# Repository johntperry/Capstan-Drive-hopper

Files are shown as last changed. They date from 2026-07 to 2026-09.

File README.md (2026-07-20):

# Capstan-Drive
A Capstan Drive is a cheap rope-driven speed reducer that has low backlash, low inertia, low noise, and high torque transparency. 
When it comes to building robots a Capstan Drive can be quite beneficial. This test stand has the following features:

-3D printed in PLA

-Weighs 852g

-120° rotation

-8.55:1 reduction (quasi-direct drive)

-Helical pattern on both drums for guided unraveling

-Lead screw to tension the rope

-ODrive S1 FOC Controller

-Eagle Power 90KV BLDC Motor

Test Stand5

# Attribution

Credit to Aaed Musa.

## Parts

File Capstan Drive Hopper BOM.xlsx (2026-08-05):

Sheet: Hopper BOM
 | Capstan Drive Hopper BOM
 | Part Name | Source | Price of Component / £ | Qty. Required | Qty. Desired | Qty. Desired Cost / £
Generic Parts | T-Motor P60 Pins 170KV | 3DXR (https://www.3dxr.co.uk/products/t-motor-t-motor-p60-pins?_pos=2&_sid=a328b846b&_ss=r) | 107.9 | 2 | 2 | 215.8
 | Moteus x1 Motor Controller | MJBots (https://mjbots.com/products/moteus-x1) | 130.82 | 2 | 2 | 261.64 | Get as expedited shipping such that it will get here early next week
 | Big-ticket items subtotal / £ |  |  |  |  | 477.44
 | 15x24x5mm Thin Section Bearing | Accu (https://www.accu.co.uk/thin-section-ball-bearings/986961-S61802) | 1.46-2.88 | 3 | 3 | 7.02
 | 40x50x6mm Thin Section Bearing | Amazon (https://www.amazon.co.uk/sourcing-map-6708-2RS-Groove-Bearings/dp/B085NCZBMC) | 6.49 | 4 | 4 | 25.96 | If this is not available on Amazon Business please let me know ASAP
 | Mastrant M2 Premium (100M drum) | Moonraker (https://moonrakeronline.com/mastrant-m-guy-rope) | 39.95 | 1 | 1 | 39.95
 | M2 x 14mm Phillips Pan-Head Screw | Accu (https://www.accu.co.uk/phillips-pan-head-screws/65368-SIP-M2-14-A2) | 0.04-0.84 | 8 | 12 | 2.04
 | M2 Heat-Fix Threaded Insert | Accu (https://www.accu.co.uk/brass-threaded-inserts/985938-HTFBI-M2-BR) | 0.05-0.80 | 8 | 12 | 1.68
 | M2 8mm Stand-off | Accu (https://www.accu.co.uk/threaded-standoffs/464634-HHTPS-M2-4-8-BR-NI) | 0.51-1.56 | 8 | 12 | 9.24
 | M3 Heat-Fix Threaded Insert | Accu (https://www.accu.co.uk/brass-threaded-inserts/849039-HTBTEI-M3-BR) | 0.08-0.88 | 8 | 12 | 2.4
 | M3 x 8mm Countersunk Screw | Accu (https://www.accu.co.uk/countersunk-socket-head-screws/5423-SSK-M3-8-A2) | 0.02-0.78 | 8 | 12 | 1.44
 | M3 x 40mm Cap Head Screw | Accu (https://www.accu.co.uk/metric-cap-head-screws/2807-SSC-M3-40-A2) | 0.06-0.86 | 2 | 2 | 1
 | M3 x 16mm Cap Head Screw | Accu (https://www.accu.co.uk/metric-cap-head-screws/3822-SSCF-M3-16-A2) | 0.02-0.79 | 8 | 12 | 1.56
 | M4 x 16mm Cap Head Screw | Accu (https://www.accu.co.uk/metric-cap-head-screws/3841-SSCF-M4-16-A2) | 0.04-0.83 | 8 | 12 | 1.92
 | M4 Locking Nut | Accu (https://www.accu.co.uk/hexagon-nylon-locking-nuts/7946-HNN-M4-A2) | 0.02-0.78 | 11 | 12 | 1.44
 | M4 x 28mm Pan Head Screw | Accu (https://www.accu.co.uk/torx-pan-head-screws/475422-SHP-M4-28-V2-A2) | 0.09-0.98 | 8 | 8 | 2.64
 | M4 x 40mm Cap Head Screw | Accu (https://www.accu.co.uk/metric-cap-head-screws/2833-SSC-M4-40-A2) | 0.08-0.90 | 3 | 4 | 1.48
 | M4 x 55mm Cap Head Screw | Accu (https://www.accu.co.uk/metric-cap-head-screws/2836-SSC-M4-55-A2) | 0.11-0.98 | 1 | 2 | 1.22
 | M4 x 100mm Cap Head Screw | Accu (https://www.accu.co.uk/metric-cap-head-screws/10645-SSC-M4-100-A2) | 1.58-3.63 | 1 | 2 | 6.04
 | M6 Locking Nut | Accu (https://www.accu.co.uk/hexagon-nylon-locking-nuts/7948-HNN-M6-A2) | 0.03-0.8 | 4 | 4 | 1.12
 | M6 x 150mm Cap Head Screw | Accu (https://www.accu.co.uk/metric-cap-head-screws/2890-SSC-M6-150-A2) | 0.63-2.06 | 4 | 4 | 5.52
 | M6 x 30mm Cap Head Screw | Accu (https://www.accu.co.uk/metric-cap-head-screws/2872-SSC-M6-30-A2) | 0.09-0.94 | 4 | 4 | 1.6
 | Other parts subtotal / £ |  |  |  |  | 115.27
 | Total Part Cost / £ |  |  |  |  | 592.71
 |  |  |  |  |  |  |  | 10.25

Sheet: 3D Printing
IGNORE FOR NOW
3D-Printed Parts | Part Name | Material | Weight of Component / g | Qty. Required | Qty. Desired | Qty. Cost of Material | Source from normal filament location
 | Hopper_Base PLA | PLA | 333 | 1 | 1 | 3.41325 | Est. PLA Cost Per kg / £
 | Controller_Cover PLA | PLA | 19.14 | 2 | 2 | 0.39237
 | Cover_Under PLA | PLA | 98.47 | 1 | 1 | 1.0093175
 | Cover PLA | PLA | 28.25 | 1 | 1 | 0.2895625
 | Small_Pulley Resin (2 Parts) | Resin | n/a | 1 | 2
 | Big_Drum_Hip PLA | PLA | 172.4 | 2 | 2 | 3.5342
 | Calf_Body PLA | PLA | 58.36 | 2 | 2 | 1.19638
 | Total 3DP Filament Cost / £ |  |  |  |  | 9.83508
 | Total Hopper Cost / £ |  |  |  |  | 602.54508

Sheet: Alternate Motors
 | Money Criteria |  |  |  |  |  |  | Physical Properties
 | Part Name | Source | Price of Component / £ | Shipping, VAT inc.? | Qty. Required | Qty. Desired | Qty. Desired Cost / £ | Mass / g | Operating Voltage / V | Peak cont. power / W | KV Value / RPM/V | Peak Current / A | Stall torque (est) / Nm | ST per kg / Nm/kg
Current | Eaglepower 8308 KV90 | AliExpress (https://www.aliexpress.com/item/1005003421356221.html) | 65.72 |  | 2 | 2 | 131.44 | 336 |  | 900 | 90 | 22 | 2.334272499 | 6.947239579 | Aaed Musa's Design (https://www.aaedmusa.com/projects/capstandrive)
 | MAD Components M6C06 | MAD (https://mad-motor.com/products/m6c06-eee-v3-brushless-drone-motor?VariantsId=11290) | 74.43 |  | 2 | 2 | 148.86 | 157 |  | 1075 | 160 | 22.43 | 1.338692015 | 8.526700733
 | MAD Components M8S C08 | MAD (https://mad-motor.com/products/m8s-c08-ipe-brushless-drone-motor) | 202.62 |  | 2 | 2 | 405.24 | 280 |  | 1490 | 100 | 31.8 | 3.036676314 | 10.84527255
 | Hobbywing M6215-HIGHTPROT | Hobbywing (https://hobbywinguav.com/product/m6215-hightprot/) | 59.03 |  | 2 | 2 | 118.06 | 270 |  | 950? | 160 | 38.6 | 2.303767801 | 8.532473338 | French Warehouse, Conflicting Pmax information
 | Hobbywing M8110 Light | Hobbywing (https://hobbywinguav.com/product/m8110-light/) | 88.97 |  | 2 | 2 | 177.94 | 300.5 |  | 2000? | 95 | 43.3 | 4.352468865 | 14.4840894 | French Warehouse, Conflicting Pmax information
 | Hobbywing M8108 Light | Hobbywing (https://hobbywinguav.com/product/m8108-light/) | 91.53 |  | 2 | 2 | 183.06 | 238.3 |  | 950? | 100 | 33.8 | 3.227662246 | 13.54453313 | French Warehouse, Conflicting Pmax information
 | T-Motor Antigravity MN5006 | 3DXR (https://www.3dxr.co.uk/products/t-motor-antigravity-5006) | 84.99 |  | 2 | 2 | 169.98 | 108 |  | 500 | 300 | 20 | 0.6366197724 | 5.894627522
 | T-Motor Antigravity 5008 170KV | 3DXR (https://www.3dxr.co.uk/products/t-motor-antigravity-5008) | 89.99 |  | 2 | 2 | 179.98 | 128 |  | 720 | 170 | 15 | 0.8425849928 | 6.582695257
 | T-Motor Antigravity 5008 340KV | 3DXR (https://www.3dxr.co.uk/products/t-motor-antigravity-5008) | 89.99 |  | 2 | 2 | 179.98 | 135 |  | 760 | 340 | 35 | 0.983015825 | 7.281598704
 | T-Motor MN4112 320KV | 3DXR (https://www.3dxr.co.uk/products/t-motor-mn4112) | 92.99 |  | 2 | 2 | 185.98 | 172 |  | 910 | 320 | 40 | 1.193662073 | 6.939895774
 | T-Motor MN5208 340KV | 3DXR (https://www.3dxr.co.uk/products/t-motor-mn5208-kv340) | 99.9 |  | 2 | 2 | 199.8 | 196 | 24 | 850 | 340 | 35 | 0.983015825 | 5.015386862
 | T-Motor MN501-S 240KV | 3DXR (https://www.3dxr.co.uk/products/t-motor-mn501-s) | 99.9 |  | 2 | 2 | 199.8 | 170 | 25-50 | 1200 | 240 | 25 | 0.9947183943 | 5.851284672
 | T-Motor MN501-S 300KV | 3DXR (https://www.3dxr.co.uk/products/t-motor-mn501-s) | 99.9 |  | 2 | 2 | 199.8 | 170 | 25-30 | 1000 | 300 | 40 | 1.273239545 | 7.489644381
 | T-Motor P60 Pins 170KV | 3DXR (https://www.3dxr.co.uk/products/t-motor-t-motor-p60-pins?_pos=2&_sid=a328b846b&_ss=r) | 107.9 |  | 2 | 2 | 215.8 | 375 | 48 | 1800 | 170 | 38 | 2.134548649 | 5.692129729
 | T-Motor P60 Pins 340KV | 3DXR (https://www.3dxr.co.uk/products/t-motor-t-motor-p60-pins) | 107.9 |  | 2 | 2 | 215.8 | 375 | 24 | 1550 | 340 | 65 | 1.825600818 | 4.868268848
 | T-Motor MN5212 340KV | 3DXR (https://www.3dxr.co.uk/products/t-motor-multirotor-fixed-wing-mn5212-motor?_pos=2&_fid=cc783bb3e&_ss=c) | 109.9 |  | 2 | 2 | 219.8 | 205 | 24 | 840 | 340 | 35 | 0.983015825 | 4.795199146 | Stanford Doggo (https://github.com/Nate711/StanfordDoggoProject)
 | T-Motor V505 | 3DXR (https://www.3dxr.co.uk/products/t-motor-v505) | 119.99 |  | 2 | 2 | 239.98 | 215 | 40-50 | 2500 | 260 | 52 | 1.909859317 | 8.883066591
 | T-Motor VL5009 KV275 | 3DXR (https://www.3dxr.co.uk/products/t-motor-vl5009-kv275) | 129 |  | 2 | 2 | 258 | 280 | 40-50 | 930 | 275 | 52 | 1.805685173 | 6.448875616
 | T-Motor Antigravity 6007II 160KV | 3DXR (https://www.3dxr.co.uk/products/t-motor-antigravity-6007ii) | 129.99 |  | 2 | 2 | 259.98 | 159 | 40-50 | 1120 | 160 | 23.7 | 1.414489557 | 8.896160734
 | T-Motor Antigravity 6007II 320KV | 3DXR (https://www.3dxr.co.uk/products/t-motor-antigravity-6007ii) | 129.99 |  | 2 | 2 | 259.98 | 161 | 24 | 1040 | 320 | 44.2 | 1.318996591 | 8.192525409
 | T-Motor VL6011 KV180 | 3DXR (https://www.3dxr.co.uk/products/t-motor-vl6011-kv180) | 139 |  | 2 | 2 | 278 | 300 | 40-50 | 2450 | 180 | 55 | 2.917840623 | 9.726135411
 | T-Motor V602 | 3DXR (https://www.3dxr.co.uk/products/t-motor-v602) | 139.9 |  | 2 | 2 | 279.8 | 345 | 40-50 | 2000 | 180 | 45 | 2.387324146 | 6.919780134
 | T-Motor U8II KV85 | 3DXR (https://www.3dxr.co.uk/products/t-motor-u8ii?variant=63500341182813) | 309.99 |  | 2 | 2 | 619.98 | 277 |  | 916.8 | 85 | 19.1 | 2.145783115 | 7.746509441
 | T-Motor U8II KV100 | 3DXR (https://www.3dxr.co.uk/products/t-motor-u8ii?variant=63500341182813) | 309.99 |  | 2 | 2 | 619.98 | 272 |  | 1406.4 | 100 | 29.3 | 2.7979439 | 10.28655845

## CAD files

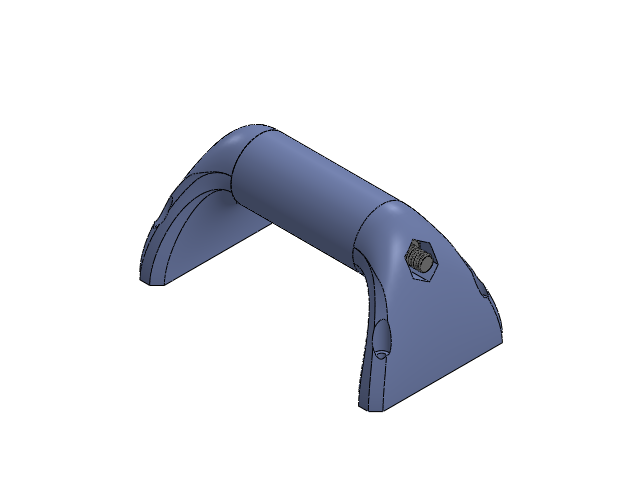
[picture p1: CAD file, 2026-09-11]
SOLIDWORKS Files/Handle_wH.SLDASM
Handle_Central_Section
Handle_Head_Side
Handle_Nut_Side
M6x75mm_Socket_Cap_Head_Screw.stp
M6_Locking_Nut.stp

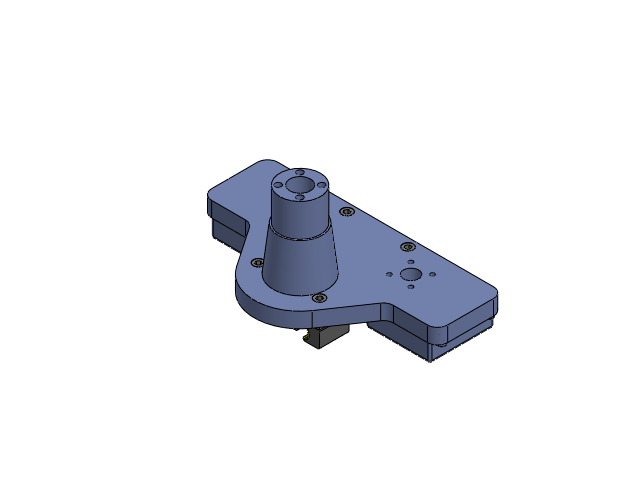
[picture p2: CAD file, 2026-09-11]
SOLIDWORKS Files/Hopper_Base_Assembly_P60.SLDASM
Hopper_Base_P60
ww-10-40-10_01
ww-10-40-10_02
ww-10-40-10_03
ww-10-40-10_04
ww-10-40-10_05
ww-10-40-10_06
ww-10-40-10_07
ww-10-40-10_08
ww-10-40-10_09
ww-10-40-10_10
ww-10-40-10_11
ww-10-40-10_12
ww-10-40-10_13
M6x30mm_Socket_Cap_Head_Screw.stp x 4
M3x10mm_Countersunk_Screw.stp x 8
M3-Threaded_Insert.stp x 10
Controller_Cover_P60 x 2
20250427-moteus-x1-r1.step x 2
M2-Threaded_Insert x 8
M2x8mm_Threaded_Hexagon_Spacer x 8
M2x14mm_Phillips_Pan_Head_Screw x 8

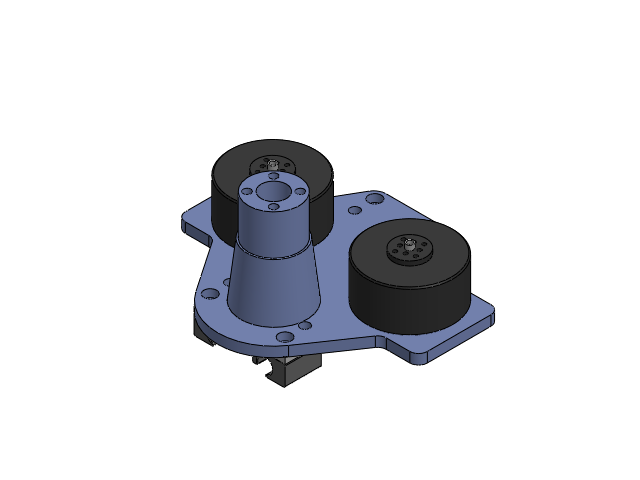
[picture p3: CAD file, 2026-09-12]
SOLIDWORKS Files/Redesign_for_motor_magnets/Base_Assembly_Redesign.SLDASM
Hopper_Base_P60_controllers_corrected
20250427-moteus-x1-r1.step x 2
T-Motor_P60 x 2
Slide_Rail_Carriage
ww-10-40-10_01
ww-10-40-10_02
ww-10-40-10_07
ww-10-40-10_11

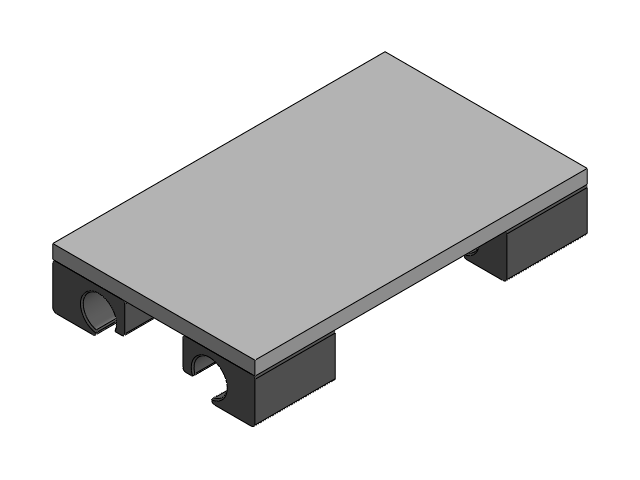
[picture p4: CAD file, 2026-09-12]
SOLIDWORKS Files/Redesign_for_motor_magnets/Extended_Carriage.SLDASM
Slide_Rail_Carriage
ww-10-40-10_01
ww-10-40-10_02
ww-10-40-10_07
ww-10-40-10_11

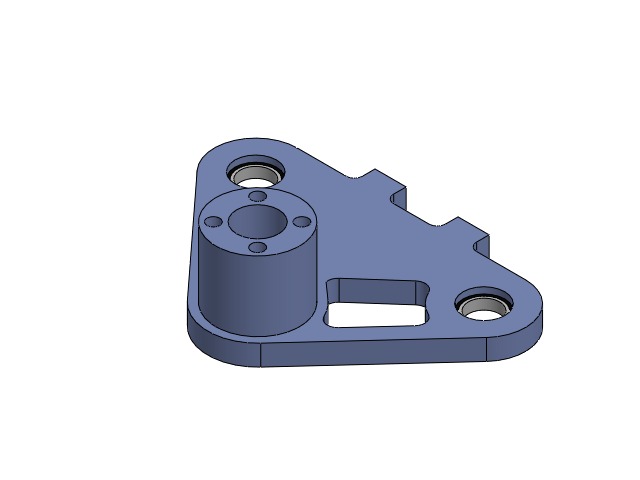
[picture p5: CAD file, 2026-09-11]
SOLIDWORKS Files/Cover_Under_thickened_wH.SLDASM
Cover_Under_M6_thickened
15x24x5mm_Thin_section_bearing x 2
M3-Threaded_Insert x 2

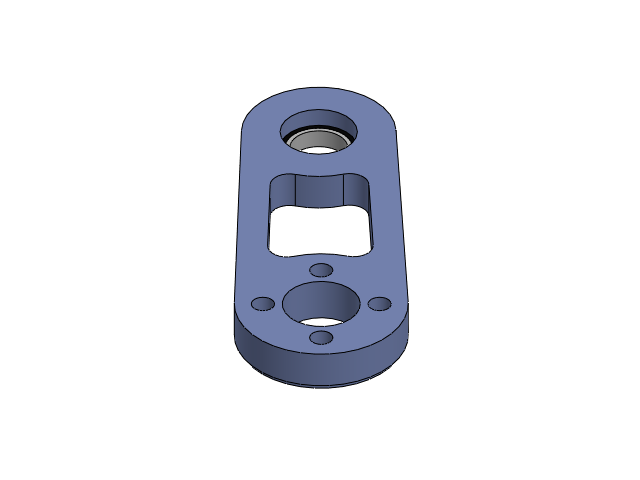
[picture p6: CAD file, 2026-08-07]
SOLIDWORKS Files/Cover_thickened_wH.SLDASM
Cover_M6_thickened
15x24x5mm_Thin_section_bearing

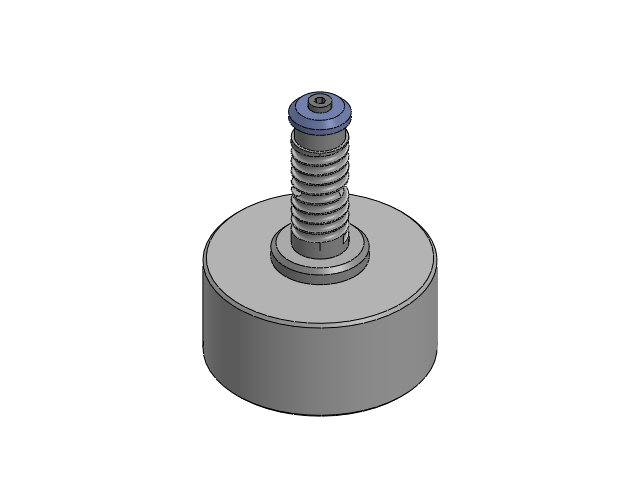
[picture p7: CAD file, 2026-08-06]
SOLIDWORKS Files/P60_with_Hardware.SLDASM
T-Motor_P60
Short_Pulley_Shaft_P60
Pulley_Cap_P60
M4x55mm_Socket_Cap_Head_Screw.stp

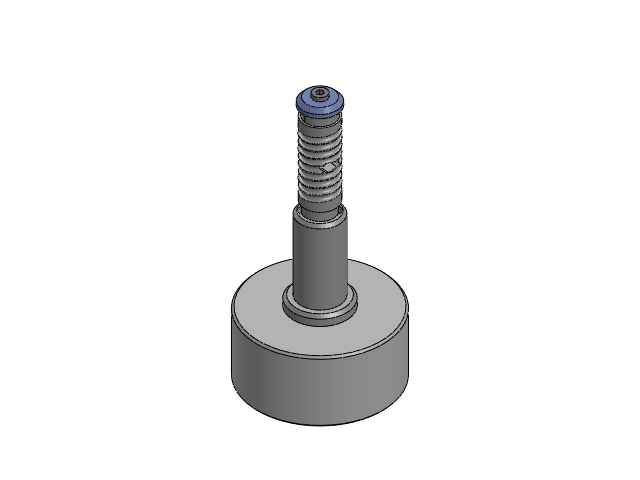
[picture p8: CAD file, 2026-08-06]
SOLIDWORKS Files/Long_P60_with_Hardware.SLDASM
Pulley_Base_P60
T-Motor_P60
Long_Pulley_Mid_Section_P60
Pulley_Cap_P60
M4x100mm_Socket_Cap_Head_Screw.stp
M3x40mm_Socket_Cap_Head_Screw.stp x 2

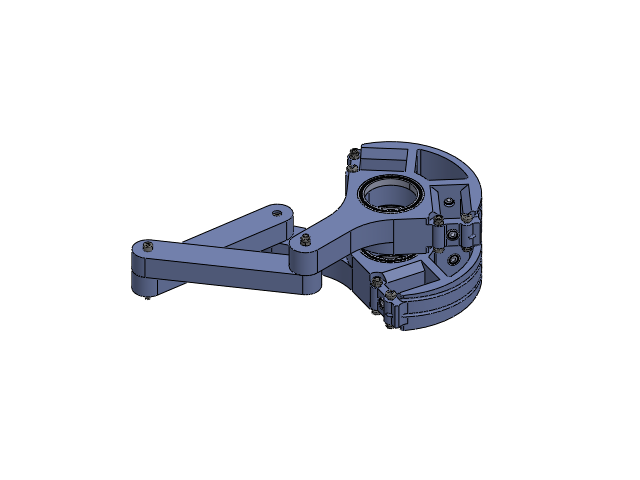
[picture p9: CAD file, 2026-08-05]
SOLIDWORKS Files/Legs_Assembly.SLDASM
Big_Drum_Hip x 2
3x10x4mm_Sealed_Bearing x 8
40x50x6_Thin_section_bearing x 4
M4_Locking_Nut.stp x 11
M4x28mm_Pan_Head_Screw.stp x 8
Calf_Body x 2
M4x40mm_Socket_Cap_Head_Screw.stp x 2
M4x45mm_Socket_Cap_Head_Screw.stp

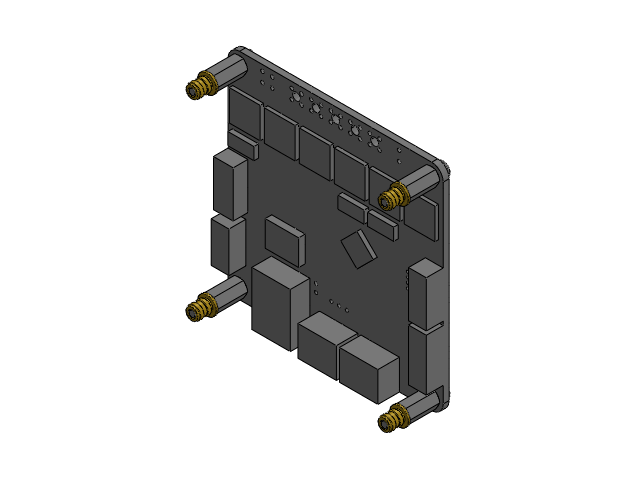
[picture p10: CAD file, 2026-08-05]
SOLIDWORKS Files/Moteus-x1_wH.SLDASM
20250427-moteus-x1-r1.step
M2-Threaded_Insert x 4
M2x8mm_Threaded_Hexagon_Spacer x 4
M2x14mm_Phillips_Pan_Head_Screw x 4

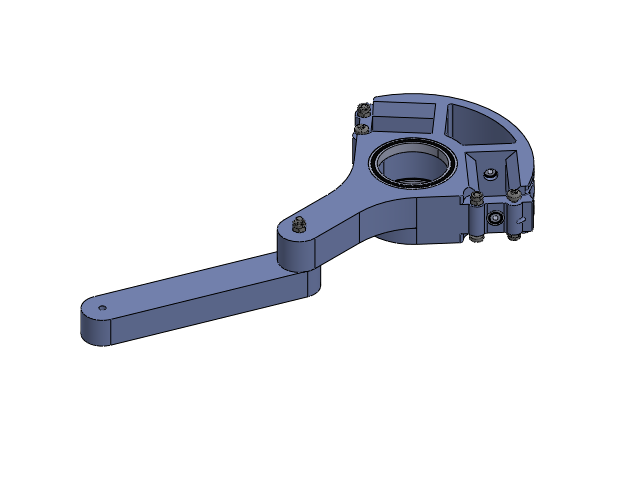
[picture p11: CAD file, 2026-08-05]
SOLIDWORKS Files/Single_Leg_Assembly.SLDASM
Big_Drum_Hip
3x10x4mm_Sealed_Bearing x 4
40x50x6_Thin_section_bearing x 2
M4_Locking_Nut.stp x 5
M4x28mm_Pan_Head_Screw.stp x 4
Calf_Body
M4x40mm_Socket_Cap_Head_Screw.stp

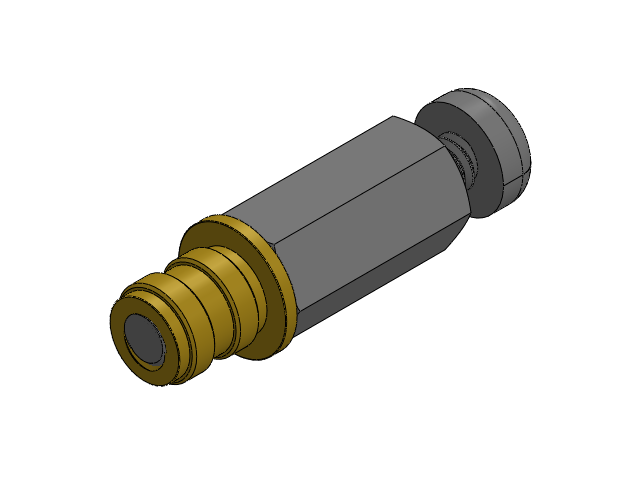
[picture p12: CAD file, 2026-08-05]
SOLIDWORKS Files/M2_Standoff_Assembly.SLDASM
M2-Threaded_Insert
M2x8mm_Threaded_Hexagon_Spacer
M2x14mm_Phillips_Pan_Head_Screw

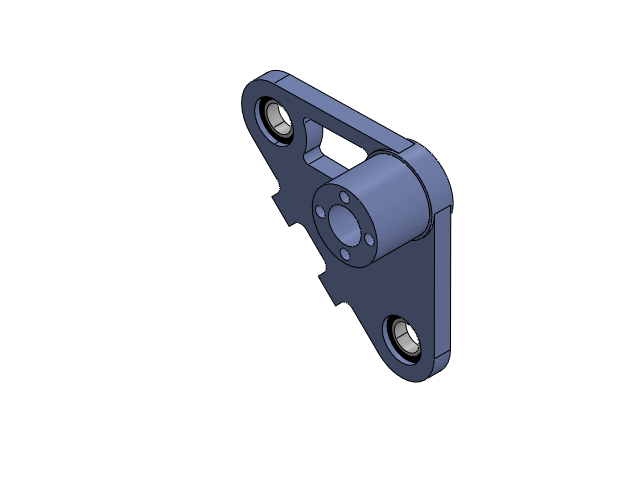
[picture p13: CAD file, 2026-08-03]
SOLIDWORKS Files/Cover_Under_M6_with_Hardware.SLDASM
Cover_Under_M6
15x28x7_Bearing x 2
M3-Threaded_Insert.stp x 2

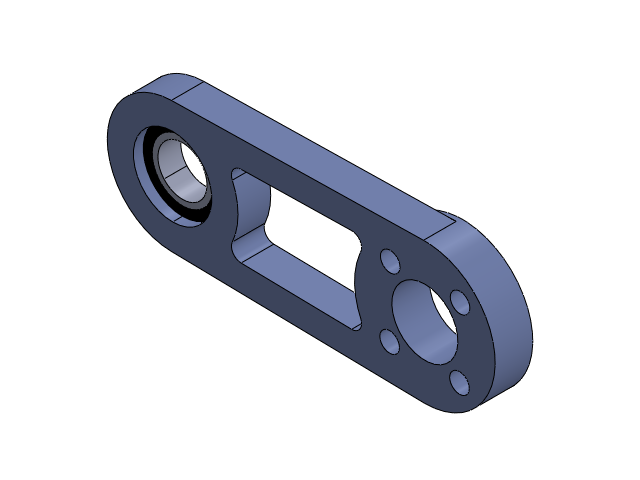
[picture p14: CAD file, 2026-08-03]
SOLIDWORKS Files/Cover_M6_with_Hardware.SLDASM
Cover_M6
15x28x7_Bearing

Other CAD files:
SOLIDWORKS Files/Test_Stand_Assembly.SLDASM
SOLIDWORKS Files/Hip_with_Hardware.SLDASM
SOLIDWORKS Files/Full_Hopper_Assembly_P60.SLDASM
SOLIDWORKS Files/Full_Hopper_Assembly.SLDASM
SOLIDWORKS Files/15x28x7_Bearing.SLDPRT
SOLIDWORKS Files/40x50x6_Thin_section_bearing.SLDPRT
SOLIDWORKS Files/Base_Rail_connection.SLDASM
SOLIDWORKS Files/Big_Drum.SLDPRT
SOLIDWORKS Files/Big_Drum_Hip.SLDPRT
SOLIDWORKS Files/Calf_Body.SLDPRT
SOLIDWORKS Files/Controller_Cover.SLDPRT
SOLIDWORKS Files/Controller_Cover_P60.SLDPRT
SOLIDWORKS Files/Cover.SLDPRT
SOLIDWORKS Files/Cover_M6.SLDPRT
SOLIDWORKS Files/Cover_M6_thickened.SLDPRT
SOLIDWORKS Files/Cover_Under.SLDPRT
SOLIDWORKS Files/Cover_Under_M6.SLDPRT
SOLIDWORKS Files/Cover_Under_M6_thickened.SLDPRT
SOLIDWORKS Files/Cover_Under_with_Hardware.SLDASM
SOLIDWORKS Files/Cover_with_Hardware.SLDASM
SOLIDWORKS Files/Fulvio_Motors_Stand/Stand_Base.SLDPRT
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

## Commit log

2026-07-21 Converted a large number of components into SLDPRT, SLDASM, begun work on replicating the hopper.
    [15x28x7_Bearing.SLDPRT, 40x50x6_Thin_section_bearing.SLDPRT, Big_Drum.SLDPRT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]
2026-07-21 Most hopper components now added, need to work on a base assembly to attach to rail.
    [Cover_Under.SLDPRT, Full_Hopper_Assembly.SLDASM, Long_Pulley_Assembly.SLDASM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]
2026-07-22 Continued work on Hopper, begun finishing work on base such that it is securely fastened.
    [Base_Rail_connection.SLDASM, Cover_Under.SLDPRT, Full_Hopper_Assembly.SLDASM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]
2026-07-22 Finished a rough design of all parts together, with the connection to the linear rail designed in.
    [Base_Rail_connection.SLDASM, Cover.SLDPRT, Cover_Under.SLDPRT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]
2026-07-25 Updated simulation files and properties.
    [Base_Rail_connection.SLDASM, Big_Drum_Hip.SLDPRT, Calf_Body.SLDPRT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]
2026-07-26 Updated Full Hopper Assembly to add subassemblies with appropriate components.
    Added the majority of hopper hardware, ready to write a BOM for the initial Hopper Design.
    [Base_Rail_connection.SLDASM, Calf_Body.SLDPRT, Cover_Under.SLDPRT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]
2026-07-26 Approximately finished the first design, ready to write up a BOM.
    [Big_Drum_Hip.SLDPRT, Calf_Body.SLDPRT, Full_Hopper_Assembly.SLDASM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]
2026-07-28 Added STEP files for 3D printing, added a motor choice section to the Hopper BOM spreadsheet.
    [Base_Rail_connection.SLDASM, Big_Drum_Hip.SLDPRT, Big_Drum_Hip.STEP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]
2026-07-30 Updated the design (mostly) to include the T-Motor P60 Motor.
    Still need to add the updated motor controllers on the rear, as well as connection between motor and Base.
    [Capstan Drive Hopper BOM.xlsx, Cover.SLDPRT, Cover_M6.SLDPRT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]
2026-08-03 Many changes to assembly to get files ready for first full print.
    [15x28x7_Bearing.SLDPRT, 40x50x6_Thin_section_bearing.SLDPRT, Big_Drum_Hip.SLDPRT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]
2026-08-05 Parts on first assembly.
    [Calf_Body.SLDPRT, Capstan Drive Hopper BOM.xlsx, Cover_Under_M6_thickened.SLDPRT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]
2026-08-06 Updated both cover sections with 3D-print compensation.
    [Cover_M6_thickened.SLDPRT, Cover_Under_M6_thickened.SLDPRT]
2026-08-06 Updated all pulley sections with updated lengths accommodating 3DP tolerance.
    [Long_P60_with_Hardware.SLDASM, Long_Pulley_Mid_Section_P60.SLDPRT, P60_with_Hardware.SLDASM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]
2026-08-06 Updated the base section with changes to improve performance of 3DP part. Added (preliminary) through-holes to allow motor wires to be routed through the section.
    [Cover_Under_thickened_wH.SLDASM, Cover_thickened_wH.SLDASM, Hopper_Base_Assembly_P60.SLDASM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]
2026-08-06 Altered the handle section to construct parts which may be 3D printed. Updated some material properties to allow for accurate simulation.
    [Handle_Central_Section.SLDPRT, Handle_Head_Side.SLDPRT, Handle_Nut_Side.SLDPRT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]
2026-08-07 Updated small bearing recesses to match changes to pulley components.
    [Cover_M6_thickened.SLDPRT, Cover_Under_M6_thickened.SLDPRT]
2026-08-07 Updates to channels within the base for motor cables.
    [Big_Drum_Hip.SLDPRT, Big_Drum_Hip.STEP, Cover_Under_thickened_wH.SLDASM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]
2026-08-07 Updated the assembly to have a proper handle assembly.
    [Handle_wH.SLDASM]
2026-08-07 Updated new standoff for cover_under.
    [Cover_Under_M6_thickened.SLDPRT, Hopper_Base_P60.SLDPRT]
2026-09-11 Begun the process of updating the physical design with correct locations of encoders for the moteus x1.
    [Base_Assembly_Redesign.SLDASM, Cover_Under_thickened_wH.SLDASM, Extended_Carriage.SLDASM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]
2026-09-12 Updated 3D files to change motor controller location, along with improved connection using threaded inserts of the long M6 bolts.
    [Base_Assembly_Redesign.SLDASM, Extended_Carriage.SLDASM, Hopper_Base_P60_controllers_corrected.SLDPRT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]
2026-09-16 Updated BOM at project end.
2026-10-14 Updated the carriage document for new design. Added drawing as well.
